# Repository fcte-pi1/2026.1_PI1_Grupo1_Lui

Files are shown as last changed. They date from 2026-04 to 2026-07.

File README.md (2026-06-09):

## Executando o Projeto (Software)

Para testar o Micromouse na sua máquina local, utilizamos um `Makefile` na raiz do projeto que facilita a inicialização simultânea de todos os serviços (Backend, Frontend e Simulador Mock).

**1. Instale as dependências (Primeira vez apenas):**
```bash
make install
```

**2. Rode todos os serviços juntos:**
```bash
make run
```

Ao fazer isso, o sistema irá subir o Backend Node.js, a Dashboard em React e o emissor de telemetria UDP do Mock em paralelo. Pressione `Ctrl + C` uma única vez para derrubar tudo.

Caso prefira rodar ou manipular módulos específicos:
- `make backend` (Sobe apenas o Node.js)
- `make frontend` (Sobe apenas a dashboard)
- `make mock` (Sobe o emissor UDP)
- `make build` (Gera a versão de produção do frontend)
- `make clean` (Apaga todas as pastas `node_modules` e pastas de `build` compiladas)

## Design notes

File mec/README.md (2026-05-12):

# 🏁 Labirinto Micromouse — Projeto em CATIA

> Modelagem 3D do labirinto para a competição **Micromouse** — Projeto Integrador 1 (PI1) | FCTE — 2026/1

---

## Tabela de Versionamento

| Versão | Descrição | Autor(es) | Revisor |
|---|---|---|---|
| 1.0 | Labirinto Micromouse — Projeto em CATIA | [Alexandre Macedo Alvarez](https://github.com/alexandremacedoalvarez-cpu) | iancostag, biancazero |

---

## 📌 Sobre o Projeto

Este repositório contém os arquivos de modelagem 3D (CATIA V5) do labirinto utilizado nos testes do robô autônomo *Micromouse*. O labirinto foi projetado para replicar fielmente as condições da competição oficial, sendo utilizado pela equipe como pista de testes durante o desenvolvimento do robô.

O *Micromouse* é um robô autônomo que resolve labirintos sem intervenção humana, mapeando o ambiente, monitorando sua localização e detectando quando alcançou o objetivo central.

---

## 📐 Especificações Técnicas

### Dimensões e Geometria

| Componente | Dimensões |
|---|---|
| **Pilar** | 5 mm × 5 mm |
| **Parede** | 180 mm (comprimento) × 50 mm (altura) |
| **Placa Base** | 720 mm × 720 mm |
| **Encaixe** | Furos de 5 mm × 5 mm nas extremidades das paredes |

### Configuração da Grade

- **Tipo:** 4×4 células
- **Lado total:** 720 mm
- **Tamanho de célula:** 18 cm × 18 cm
- **Espaçamento entre centros de pilares:** 175 mm
- **Vão livre (corredor):** 170 mm de largura — espaço suficiente para o robô (máx. 25 cm) manobrar sem colisões

> **Justificativa do espaçamento de 175 mm:** o conjunto de 5 pilares por linha cabe exatamente dentro da placa de 720 mm, sem extrapolação das bordas, enquanto mantém o corredor mínimo necessário para navegação do robô.

### Padrão de Cores

| Elemento | Cor |
|---|---|
| Corpo (paredes/pilares) | Branco  |
| Topo das peças | Vermelho  |
| Placa Base | Preto |

> As cores seguem o padrão oficial da competição Micromouse.

---

## 🔩 Decisões de Modelagem

- **Travamento mecânico modular:** as paredes possuem furos de 5×5 mm nas extremidades que encaixam sobre os pilares, criando uma estrutura firme e reconfigurável — o arranjo das paredes pode ser alterado para gerar diferentes labirintos.
- **Organização do modelo:** planos auxiliares e *constraints* foram ocultados na montagem final para limpeza visual do modelo.
- **Abordagem *bottom-up*:** as peças foram modeladas individualmente (`CATPart`) e depois montadas progressivamente em produtos (`CATProduct`), do nível de célula até o labirinto completo.

---

## 🎯 Contexto — Competição Micromouse (PI1 2026/1)

A equipe deve construir um robô autônomo capaz de resolver três labirintos de complexidade crescente:

| Labirinto | Grade | Dimensão |
|---|---|---|
| 1º | 4×4 | 72 cm |
| 2º | 8×8 | 144 cm |
| 3º | 16×16 | 288 cm |

**Este repositório cobre o labirinto 4×4 de testes**, construído pela equipe para desenvolvimento e validação do robô antes das etapas oficiais.

---

## 🛠️ Software Utilizado

- **CATIA V5** — Modelagem e montagem 3D

---

*Repositório seguindo o template disponibilizado em [github.com/fcte-pi1/template](https://github.com/fcte-pi1/template)*

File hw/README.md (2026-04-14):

# _Hardware_

Esta pasta deverá armazenar arquivos referentes a:

- Simulações de circuitos eletrônicos (alimentação, sensores, atuadores etc.): [Qucs](https://qucs.sourceforge.net/), [QSPICE](https://www.qorvo.com/design-hub/design-tools/interactive/qspice), [Fritzing](https://fritzing.org/), dentre outros.
- Esquemáticos de circuitos: [KiCad](https://www.kicad.org/), Qucs, QSPICE.
- Diagramas de bloco: [Canva](https://www.canva.com/pt_br/), [TikZ](https://tikz.net/).
- _Datasheets_ de componentes eletrônicos, microcontroladores, _shields_ Arduino, motores etc.
- Testes tabelados de circuitos: arquivos CSV, Excel.
- Imagens PNG e JPEG de resultados práticos: fotos de testes reais, gráficos de resultados etc.
- Outros arquivos referentes ao _hardware_ do projeto.

> [!WARNING]
> **Não acrescente código-fonte a esta pasta.** O código desenvolvido para microcontroladores e SOCs ([Arduino](https://www.arduino.cc/), [ESP32](https://www.espressif.com/), [Raspberry Pi](https://www.raspberrypi.com/)) deverá ser armazenado na pasta [src/firmware](https://github.com/fcte-pi1/template/tree/main/src/firmware) deste repositório.

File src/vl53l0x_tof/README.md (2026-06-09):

# VL53L0X ToF com ESP-IDF

Projeto ESP-IDF para ler um sensor ToF VL53L0X via I2C.

Este projeto usa o componente `ESP32_VL53L0X` copiado do projeto `example`, porque ele implementa o acesso de registrador do VL53L0X com indice de 8 bits. Os exemplos genericos de sensores I2C do ESP-IDF costumam assumir registradores de 16 bits e nao servem diretamente para esse sensor.

## Ligacao padrao

| VL53L0X | ESP32 |
| --- | --- |
| VIN/VCC | 3V3 |
| GND | GND |
| SDA | GPIO21 |
| SCL | GPIO22 |
| XSHUT | opcional |

O endereco I2C padrao do VL53L0X e `0x29`.

Se voce conectou o pino `XSHUT`, edite `main/app_main.cpp` e troque:

```cpp
constexpr gpio_num_t kXshutPin = GPIO_NUM_MAX;
```

por exemplo:

```cpp
constexpr gpio_num_t kXshutPin = GPIO_NUM_18;
```

## Build e flash

```sh
cd /home/mauricio/esp/vl53l0x_tof
. ../esp-idf/export.sh
idf.py set-target esp32
idf.py build
idf.py -p /dev/ttyUSB0 flash monitor
```

Troque `/dev/ttyUSB0` pela porta serial da sua placa.

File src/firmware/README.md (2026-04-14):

# _Firmware_
Esta pasta deverá armazenar arquivos referentes a:

- Código-fonte para microcontroladores e SOCs: [Arduino](https://www.arduino.cc/), [ESP32](https://www.espressif.com/), [Raspberry Pi](https://www.raspberrypi.com/), dentre outros.
- Projetos de organização destes códigos, caso utilize IDEs: [Arduino IDE](https://www.arduino.cc/en/software/), [Visual Studio](https://visualstudio.microsoft.com/pt-br/downloads/) etc.
- Arquivos de configuração: ```CMakeLists.txt``` se for usar [CMake](https://cmake.org/download/), ```Makefile``` se for usar [make](https://www.cs.colby.edu/maxwell/courses/tutorials/maketutor/) etc.

Evite incluir:
- Artefatos de compilação: os arquivos de saída compilados (binários, arquivos objeto, .hex, .elf) devem ser gerados pelo processo de compilação e não incluídos no repositório.
- Arquivos temporários/específicos do sistema operacional: Arquivos como .DS_Store (macOS) ou arquivos de configuração do editor (a menos que esteja usando uma configuração compartilhada como .editorconfig).
- Configurações pessoais: Arquivos de configuração locais específicos da máquina do desenvolvedor.

> [!WARNING]
> **Não acrescente arquivos referentes a _hardware_ nesta pasta.** Eles deverão ser armazenados na pasta [hw](https://github.com/fcte-pi1/template/tree/main/hw) deste repositório.

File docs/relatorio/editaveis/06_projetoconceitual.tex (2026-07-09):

\chapter{Projeto Conceitual do Produto}

\label{projeto}

\section{Características gerais}

%\textcolor{red}{Descrever produto de forma geral. Apresentar itens teóricos sobre o projeto a serem aprofundados ou detalhados oportunamente.}

%\textcolor{red}{Apresentar e explicar a Estrutura Analítica do Projeto (EAP), tomando cuidado com a legibilidade da imagem. Se necessário, coloque a EAP dentro do comando ``\textsf{\textbackslash begin\{landscape\} \textbackslash end\{landscape\}}'' para que ela seja apresentada em uma página deitada.}

O Micromouse é um robô móvel autônomo desenvolvido para mapear e resolver labirintos desconhecidos em matrizes de $4\times4$, $8\times8$ e $16\times16$ células, com o objetivo de alcançar a região central no menor tempo possível. O produto integra tecnologias multidisciplinares, unindo uma estrutura física compacta a um ecossistema de software para monitoramento em tempo real.

O hardware é baseado no microcontrolador ESP32, utilizando sensores laser Time-of-Flight (ToF) para detecção de obstáculos e motores N20 com encoders para odometria. O sistema de software provê a observabilidade através de um dashboard web que exibe dados de telemetria, como trajeto, velocidade e consumo de bateria via Wi-Fi.

Os itens teóricos fundamentais para o sucesso do projeto, que serão detalhados oportunamente, compreendem:

\begin{itemize}
    \item \textbf{Dinâmica e Estabilidade}: Cálculos de torque, potência e análise das condições de não-tombamento para garantir manobras seguras.
    \item \textbf{Gestão Energética}: Dimensionamento de baterias Li-Ion e eficiência de conversores DC-DC Buck para autonomia operacional.
    \item \textbf{Algoritmos de Navegação}: Aplicação de lógica Flood Fill para resolução de caminho e estratégias de exploração como DFS ou Tremaux.
    \item \textbf{Arquitetura de Sistemas}: Uso do FreeRTOS para processamento dual-core paralelo entre controle e telemetria.
\end{itemize}

\subsection{Estrutura Analítica do Projeto}

A Estrutura Analítica do Projeto (EAP) apresentada nesta seção é uma decomposição hierárquica orientada a entregas, porém, com foco no produto, organizada para facilitar o gerenciamento e o controle do escopo. O produto, e consequentemente o projeto, está dividido em cinco macroáreas principais:

\begin{itemize}
    \item \textbf{Estruturas (Laranja):} Abrange o desenvolvimento da estrutura física do robô e do labirinto de teste, incluindo base, chassi, fixações, rodas e organização mecânica.

    \item \textbf{Energia (Rosa):} Envolve a definição e integração do sistema de alimentação, incluindo bateria, reguladores de tensão, distribuição de energia e proteção do circuito.

    \item \textbf{Sistema de software (Verde):} Abrange o desenvolvimento da lógica de controle do robô, incluindo leitura dos sensores, controle dos motores, algoritmo de navegação e comunicação com o sistema embarcado.

    \item \textbf{Sistema eletrônico embarcado (Azul):} Envolve a integração dos componentes eletrônicos, como microcontrolador, sensores, driver dos motores, encoders e conexões elétricas do robô.

    \item \textbf{Sistema integrado (Roxo):} Abrange a integração entre estrutura, energia, eletrônica e software, incluindo montagem final, testes de funcionamento, ajustes e validação do robô no labirinto.
\end{itemize}

\begin{landscape}

\begin{figure}[p]
    \centering
    \includegraphics[
        width=\linewidth,
        height=0.80\textheight,
        keepaspectratio
    ]{figuras/eap.jpg}
    \caption{Visualização geral da Estrutura Analítica do Projeto.}
    \label{fig:eap-geral}
\end{figure}

\end{landscape}

\begin{landscape}

\begin{figure}[p]
    \centering

    \begin{minipage}{0.48\linewidth}
        \centering
        \includegraphics[
            width=\linewidth,
            height=0.72\textheight,
            keepaspectratio
        ]{figuras/eap_estruturas_energia.jpg}

        \vspace{0.2cm}
        \textbf{(a)} Primeira parte expandida do EAP.
    \end{minipage}
    \hfill
    \begin{minipage}{0.48\linewidth}
        \centering
        \includegraphics[
            width=\linewidth,
            height=0.72\textheight,
            keepaspectratio
        ]{figuras/eap_energia_embarcados_integrado.jpg}

        \vspace{0.2cm}
        \textbf{(b)} Segunda parte expandida do EAP.
    \end{minipage}

    \caption{Visualizações expandidas da Estrutura Analítica do Projeto.}
    \label{fig:eap-expandido}
\end{figure}

\end{landscape}

\section{Estrutura}
Esta seção descreve a síntese do projeto mecânico do Micromouse, desenvolvido sob uma perspectiva técnica e funcional. A estrutura foi projetada para equilibrar a rigidez necessária à precisão dos sensores com a leveza exigida para acelerações rápidas, respeitando rigorosamente as normas internacionais de competições de Micromouse.

Para a validação das escolhas de engenharia, este documento detalha os cálculos para determinação de dimensões e seleção dos motores, desenhos técnicos que materializam a geometria adotada e a especificação técnica dos materiais aplicados tanto no chassi quanto no labirinto de testes.

\subsection{Objetivo Geral}
Projetar e validar a estrutura física de um robô autônomo (Micromouse) e seu ambiente de simulação, garantindo uma plataforma estável, leve e de baixo custo, capaz de realizar navegação precisa e manobras de alta performance em conformidade com os padrões competitivos.

\subsubsection{Objetivos Específicos}
\begin{itemize}
    \item \textbf{Dimensionamento Geométrico:} Estabelecer as dimensões críticas do chassi (largura máxima de 110 mm) para garantir a manobrabilidade em trechos retilíneos e diagonais, evitando colisões com as paredes do labirinto.
    \item \textbf{Otimização Dinâmica:} Realizar o cálculo de torque e potência para a seleção do sistema motriz (GA12-N20), assegurando que o robô vença a inércia e mantenha a estabilidade (não-tombamento) em acelerações e frenagens bruscas.
    \item \textbf{Desenvolvimento Estrutural:} Projetar um chassi estratificado (dois níveis) que organize de forma estratégica a bateria, motores e sensores, otimizando o centro de massa e facilitando a manutenção dos componentes.
    \item \textbf{Seleção de Materiais:} Justificar o uso de materiais como PLA (impressão 3D) para o robô e MDF/EVA para o labirinto, focando na redução de peso e na qualidade da leitura dos sensores.
    \item \textbf{Padronização do Ambiente:} Construir um labirinto de testes modular que replique as condições reais de competição, permitindo a calibração fina dos algoritmos de busca e mapeamento.
\end{itemize}

\subsection{Dimensionamento Geométrico do Labirinto}

\subsubsection{Contexto e Normas do Labirinto}
O labirinto oficial da competição Micromouse é composto por células quadradas de $18{ cm} \times 18{ cm}$, medidos de centro a centro das paredes. As paredes laterais possuem $5{ cm}$ de altura e $1,2{ cm}$ de espessura. Esse padrão é adotado internacionalmente e define todas as restrições geométricas para o projeto do robô.

Considerando a espessura das paredes, o vão livre disponível para a movimentação do robô dentro de um corredor retilíneo é de:
\begin{equation}
18{ cm} - 1,2{ cm} = 16,8{ cm}
\end{equation}

Este valor é crítico porque representa o espaço real que o robô tem para efetuar o deslocamento sem tocar nas paredes laterais durante uma trajetória em linha reta. Além disso, para manobras que exigem uma rotação de $90^\circ$ ou travessia diagonal de uma célula, a geometria do labirinto impõe uma restrição mais severa: o robô não pode exceder a largura equivalente à diagonal do vão livre. O limite teórico para essa situação é:
\begin{equation}
{Largura diagonal} = 16,8{ cm} \div \sqrt{2} \approx 11,88{ cm}
\end{equation}

O projeto do chassi deve respeitar ambos os limites:
\begin{itemize}
    \item $\le 16,8{ cm}$ para trechos retos;
    \item $\le 11,88{ cm}$ para garantir operação em diagonal.
\end{itemize}

\subsubsection{Materiais e Construção do Labirinto Teste}
Para a construção do labirinto de testes, o projeto priorizou a modularidade e a fidelidade técnica às normas de competição. A estrutura baseia-se em uma malha de $4 \times 4$ células, totalizando $72{ cm}$ de lado, com vãos livres de $168{ mm}$.

Optou-se por uma base em \textbf{MDF de 6 mm}, visando planicidade e uniformidade. Para as paredes, utilizou-se \textbf{EVA de alta densidade de 12 mm}, que oferece leveza e segurança contra impactos. A montagem utiliza 25 postes removíveis ancorados à base por suportes metálicos em ``L''. As faces das paredes são revestidas com vinil branco fosco para otimizar os sensores ToF. O detalhamento geométrico completo (Figura \ref{fig:Desenho esquematoco do Labirinto de Testes}) ilustra o posicionamento dos postes e as dimesões da labirinto de testes. 

\subsection{Dimensionamento Geométrico do Chassi}

\subsubsection{Arranjo Preliminar dos Componentes}
\begin{itemize}
    \item \textbf{Bateria:} Posicionada na parte traseira para estabilizar o centro de massa.
    \item \textbf{Motores:} Localizados no centro do chassi para fornecer torque equilibrado às rodas.
    \item \textbf{Sensores:} Posicionados estrategicamente na dianteira para mapeamento e detecção de obstáculos.
\end{itemize}

\subsubsection{Desenho Esquemático}
O desenho técnico do chassi segue as larguras máximas de $160{ mm}$ (retilíneo) e $118,8{ mm}$ (diagonal). A vista explodida do Robô evidencia a hierarquia de montagem e as premissas de estabilidade dinâmica e fácil acesso à manutenção através da tampa
superior.

\subsubsection{Vistas Técnicas}
O desenho técnico do chassi (Figura \ref{fig:Draft Micromouse}) apresenta as principais dimensões e a localização de fixação dos componentes (motores, bateria e microcontrolador). As cotas estão expressas em milímetros e seguem as larguras máximas definidas anteriormente:
\begin{itemize}
    \item 160 mm para deslocamento retilíneo;
    \item 118,8 mm para manobras diagonais.
\end{itemize}

\subsubsection{Vista Explodida e Arranjo de Componentes}
A vista explodida do robô (Figura \ref{fig:Draft Micromouse explodido}) evidencia a disposição espacial dos 13 subsistemas principais, permitindo visualizar a hierarquia de montagem e a integração entre as partes mecânicas e eletrônicas.

\begin{table}[htbp]
\centering
\caption{Lista de Peças}
\label{tab:pecas_micromouse}
\begin{tabular}{@{}clc@{}}
\toprule
\textbf{Número} & \textbf{Nome} & \textbf{Quantidade} \\ \midrule
1 & Chassis & 1 \\
2 & Motor & 2 \\
3 & Bateria & 1 \\
4 & Microcontrolador & 1 \\
5 & Lateral & 2 \\
6 & Roda & 4 \\
7 & Engrenagem & 2 \\
8 & Protoboard 400 pinos & 1 \\
9 & Protoboard 170 pinos & 2 \\
10 & Tampa & 1 \\
11 & Sensor Laser VL53l0x & 3 \\
12 & Conversor DC-DC & 2 \\
13 & Driver para motor & 1 \\ \bottomrule
\end{tabular}
\end{table}

O arranjo foi projetado seguindo as seguintes premissas:

\begin{itemize}
    \item \textbf{Estabilidade Dinâmica:} A bateria (item 3) e os motores (item 2) estão fixados no chassi inferior (item 1), mantendo o centro de massa o mais próximo possível do solo e garantindo estabilidade em curvas.
    \item \textbf{Acesso à manutenção:} A tampa (item 10) permite a separação funcional dos componentes. Aqueles que não necessitam de acesso constante (motores, bateria) são alocados no chassi (item 1). Os elementos que exigem intervenção constante para depuração e calibração ficam acessíveis no plano superior. Além de prover proteção passiva, a tampa integra aberturas para o gerenciamento de cabos.
    \item \textbf{Interface de sensoriamento:} Os suportes dos sensores laser (item 11) foram posicionados nas extremidades da base, assegurando que o envelope de leitura não sofra interferência das rodas ou da tampa superior.
\end{itemize}

\subsubsection{Visão Isométrica}
A perspectiva isométrica do Micromouse (Figura \ref{fig:iso do micromouse}) consolida o design tridimensional, permitindo a visualização do robô em seu estado final de montagem.

\begin{itemize}
    \item \textbf{Validação volumétrica:} Demonstra a capacidade do conjunto e seu respeito às dimensões do labirinto.
\end{itemize}

\subsection{Dimensionamento dos Motores}

Pela Segunda Lei de Newton, a força trativa ($F_t$) deve superar a resistência ao rolamento ($F_{rr}$) para imprimir uma aceleração constante ($a$):

\begin{equation}
    C_{rr} = \frac{b}{R} \quad ; \quad F_{rr} = C_{rr} \cdot m \cdot g
\end{equation}

Onde $b$ é o coeficiente de atrito de rolamento, $R$ o raio da roda, $m$ a massa ($m \le 0,250{kg}$) e $g$ a aceleração da gravidade. A força trativa total é dada por:

\begin{equation}
    F_t = m \cdot (a + C_{rr} \cdot g)
\end{equation}

O torque mínimo ($T_{\min}$) e o torque de projeto com margem ($T_{{proj}}$) são definidos, respectivamente, pelas equações \ref{eq:torque_min} e \ref{eq:torque_projeto}:

\begin{equation}
    T_{\min} = F_t \cdot R
    \label{eq:torque_min}
\end{equation}

\begin{equation}
    T_{{proj}} = T_{\min} \cdot 1,3
    \label{eq:torque_projeto}
\end{equation}

\subsubsection{Desenvolvimento Matemático}

Adotou-se $b = 1,5{mm}$ (silicone sobre madeira pintada) e $R = 22,5{mm}$. Os cálculos seguem no Sistema Internacional (SI):

\begin{equation}
    F_{rr} = \left(\frac{1,5}{22,5}\right) \cdot 0,25 \cdot 9,81 = 0,1635{N}
\end{equation}

Logo, a força trativa para uma aceleração de $1{m/s}^2$ é:

\begin{equation}
    F_t = 0,25 \cdot 1 + 0,1635 = 0,4135{N}
\end{equation}

O torque mínimo total e o torque por motor (dividido por 2 com margem de 30\%) resultam em:

\begin{equation}
    T_{\min} \approx 9,31{N.mm} \Longrightarrow T_{\min\_{motor\_proj}} = \frac{9,31 \cdot 1,3}{2} = 6,0515{N.mm}
\end{equation}

\subsubsection{Conclusão e Validação}

Comparando os valores calculados com o \textit{datasheet} do motor \textbf{GA12-N20-S0310D-E}:

\begin{table}[htbp]
    \centering
    \caption{Validação do torque do motor GA12-N20}
    \label{tab:validacao-motor}
    \small
    \renewcommand{\arraystretch}{1.5}
    \begin{tabular}{|l|c|c|c|}
        \hline
        \textbf{Parâmetro} & \textbf{Valor Datasheet} & \textbf{Valor (N.mm)} & \textbf{Status} \\ \hline
        Torque Nominal     & 2,9~kg.mm                & 28,44~N.mm            & Validado ($> 6,05$) \\ \hline
        Torque de Estol    & 17~kg.mm                 & 166,71~N.mm           & Validado ($> 6,05$) \\ \hline
    \end{tabular}
\end{table}

\subsection{Condições de Não-Tombamento}

\subsubsection{Objetivo e Fundamentação Teórica}

O objetivo desta análise é determinar a altura máxima permitida para o Centro de Gravidade (CG), de forma a garantir que o veículo permaneça estável e não capote durante frenagens bruscas.

Na iminência de tombamento, a força Normal no eixo traseiro torna-se nula. A estabilidade é mantida enquanto o torque restaurador for superior ao torque de tombamento:

\begin{itemize}
    \item \textbf{Torque Restaurador:} Gerado pela componente vertical do peso.
    \item \textbf{Torque de Tombamento:} Gerado pela força de inércia resultante da desaceleração.
\end{itemize}

\subsubsection{Desenvolvimento Matemático}

A condição de estabilidade em relação ao eixo frontal é definida por:

\begin{equation}
    \tau_{{restaurador}} \geq \tau_{{tombamento}}\Longrightarrow P \cdot x \geq F \cdot h_{{máx}}
\end{equation}

Considerando que a força de desaceleração máxima é limitada pelo atrito estático ($\mu_e$), temos $F = P \cdot \mu_e$. Assim:

\begin{equation}
    P \cdot x \geq (P \cdot \mu_e) \cdot h_{máx}\Longrightarrow h_{{máx}} \le \frac{x}{\mu_e}
\end{equation}

Para uma distribuição de massa ideal, onde o CG está no centro geométrico ($x = L/2$):

\begin{equation}
    h_{{máx}}\le\frac{L}{2\cdot\mu_e}
\end{equation}

Dados os parâmetros do projeto:
\begin{itemize}
    \item $\mu_e = 0,7$
    \item $L = 0,1225~{m}$
\end{itemize}

\begin{equation}
    h_{máx}\le \frac{0,1225}{2 \cdot 0,7} \approx 0,0875{m} \Longrightarrow h_{máx} \le 8,75{cm}
\end{equation}

\subsubsection{Conclusão}
A análise do projeto mecânico confirma que o robô está tecnicamente apto para a competição. Com largura de $110{ mm}$ e centro de gravidade otimizado, o Micromouse garante agilidade sem risco de colisões ou tombamentos. O sistema motriz validado e o labirinto de testes fiel às normas consolidam uma base sólida para a integração final dos algoritmos de navegação autônoma.

\section{Análise de consumo energético}

Esta seção apresenta o dimensionamento energético do sistema embarcado do MicroMouse, considerando os componentes eletrônicos utilizados, o tempo estimado de operação e a escolha da fonte de alimentação. O objetivo é estimar o consumo total do sistema e justificar a escolha da bateria utilizada no projeto.

\subsection{Parâmetros considerados}

Para o dimensionamento energético, considerou-se o uso do sistema durante \textbf{1080 segundo (s)}, o equivalente a 18 minutos. Esse tempo foi definido levando em conta 9 tentativas, por ser o máximo de tentativas possíveis durante a prova, e a duração de 2 minutos por tentativa.

Também foi adotada uma margem de segurança de 30\% sobre o consumo total estimado, a fim de reduzir o risco de subdimensionamento da bateria e garantir maior confiabilidade ao sistema.

\subsection{Relação dos componentes}

A Tabela~\ref{tab:componentes-energia} apresenta os principais componentes eletrônicos considerados no cálculo energético do sistema.

\begin{table}[htbp]
\centering
\caption{Componentes considerados no dimensionamento energético}
\label{tab:componentes-energia}
\small
\setlength{\tabcolsep}{4pt}
\renewcommand{\arraystretch}{1.2}
\begin{tabularx}{\textwidth}{|>{\raggedright\arraybackslash}X|c|c|c|c|}
\hline
\textbf{Componente} & \textbf{Qtd.} & \textbf{Tensão (V)} & \textbf{Corrente (A)} & \textbf{Tempo (s)} \\ \hline

ESP WROOM-32 / ESP32 DevKit V1 
& 1 & 5 & 0,08 a 0,5 & 1080 \\ \hline

Motor GA-12 N20 DC com encoder 
& 2 & 6 & 0,08 a 1,6 & 1080 \\ \hline

Sensor ToF VL53L0X 
& 3 & 2,8 & 0,02 & 1080 \\ \hline

Sensor INA219 
& 1 & 3,3 & 0,001 & 1080 \\ \hline

\end{tabularx}
\end{table}

A Ponte H TB6612FNG não foi contabilizada diretamente no dimensionamento energético, pois atua como intermediária no acionamento dos motores. Dessa forma, o consumo dos motores GA-12 N20 já representa a maior parte da corrente que passa por ela. O consumo próprio da lógica interna da TB6612FNG é muito pequeno em relação ao consumo total do sistema e, por isso, foi considerado desprezível para este cálculo.

\subsection{Cálculo da energia consumida por componente}

A energia consumida por cada componente foi calculada por meio da 
Equação~\ref{eq:energia}, utilizando os parâmetros de tensão, corrente 
e tempo listados na Tabela~\ref{tab:componentes-energia}.

\begin{equation}
E_{J} = V \cdot I \cdot t
\label{eq:energia}
\end{equation}

No qual $E$ representa a energia consumida em joules (J), $V$ é a tensão 
de operação em volts (V), $I$ é a corrente elétrica em amperes (A) e 
$t$ é o tempo de uso em segundos (s). Para os componentes com faixa de 
corrente, adotou-se o valor máximo, representando o pior caso de consumo.

Para converter o resultado de joules para watt-hora(Wh), utilizou-se a 
relação da Equação~\ref{eq:conversao_j_wh}:

\begin{equation}
E_{Wh} = \frac{E_{J}}{3600}
\label{eq:conversao_j_wh}
\end{equation}

A Tabela~\ref{tab:consumo-individual} apresenta, para cada componente, 
a aplicação da Equação~\ref{eq:energia} com os parâmetros da 
Tabela~\ref{tab:componentes-energia}, o resultado em joules,
conversão para watt-hora pela Equação~\ref{eq:conversao_j_wh} e o resultado em watt-hora.

\begin{table}[h]
\centering
\caption{Consumo energético individual dos componentes em 18 minutos}
\label{tab:consumo-individual}
\resizebox{\linewidth}{!}{
\begin{tabular}{|l|l|c|c|c|}
\hline
\textbf{Componente} & \textbf{Equação \ref{eq:energia}} & \textbf{Energia (J)} & \textbf{Equação \ref{eq:conversao_j_wh}} & \textbf{Energia (Wh)} \\ \hline
ESP32 DevKit V1 & $E_{J} = 5 \cdot 0{,}5 \cdot 1080$ & 2700 &  $E_{Wh} = 2070 \div 3600 $ & 0,75 \\ \hline
Motor GA-12 N20 & $E_{J} = 6 \cdot 1{,}6 \cdot 1080$ & 10368 & $E_{Wh} = 10368 \div 3600 $  & 2,88 \\ \hline
Sensor ToF VL53L0X & $E_{J} = 2{,}8 \cdot 0{,}02 \cdot 1080$ & 60,48 & $E_{Wh} = 60,48 \div 3600 $ & 0,0168 \\ \hline
Sensor INA219 & $E_{J} = 3{,}3 \cdot 0{,}001 \cdot 1080$ & 3,564 & $E_{Wh} = 3,564 \div 3600 $ & 0,001 \\ \hline
\end{tabular}
}
\end{table}

\subsection{Estimativa do consumo total de energia}

Para obter o consumo total, o consumo individual de cada componente foi multiplicado pela respectiva quantidade utilizada no sistema, conforme apresentado na Tabela~\ref{tab:consumo-total}.

\begin{table}[htbp]
\centering
\caption{Consumo total estimado do sistema}
\label{tab:consumo-total}
\small
\setlength{\tabcolsep}{4pt}
\renewcommand{\arraystretch}{1.2}
\begin{tabularx}{\textwidth}{|>{\raggedright\arraybackslash}X|c|c|c|}
\hline
\textbf{Componente} 
& \textbf{Qtd.} 
& \shortstack{\textbf{Consumo}\\\textbf{individual}\\\textbf{(Wh)}} 
& \shortstack{\textbf{Consumo}\\\textbf{total}\\\textbf{(Wh)}} \\ \hline

ESP32 DevKit V1 
& 1 
& 0,75 
& 0,75 \\ \hline

Motor GA-12 N20 DC com encoder 
& 2 
& 2,88 
& 5,76 \\ \hline

Sensor ToF VL53L0X 
& 3 
& 0,0168 
& 0,0504 \\ \hline

Sensor INA219 
& 1 
& 0,001 
& 0,001 \\ \hline

\textbf{Total final} 
& -- 
& -- 
& \textbf{6,5614} \\ \hline

\end{tabularx}
\end{table}

Portanto, o consumo total estimado para 18 minutos de operação é de aproximadamente:

\begin{equation}
E_{total} \approx 6{,}56\,Wh
\end{equation}

Aplicando uma margem de segurança de 30\%:

\begin{equation}
E_{folga} = 6{,}56 \cdot 1{,}30 \approx 8{,}53\,Wh
\end{equation}

Assim, a fonte de alimentação deve ser dimensionada para fornecer, no mínimo, aproximadamente \textbf{$8{,}53\,Wh$}.

\subsection{Escolha da fonte de alimentação}

Para escolher a fonte de alimentação do sistema, foi utilizada a relação entre energia, tensão e capacidade, apresentada na Equação~\ref{eq:capacidade}.

\begin{equation}
Capacidade = \frac{E}{V}
\label{eq:capacidade}
\end{equation}

Onde a capacidade é dada em ampère-hora (Ah), $E$ representa a energia necessária em watt-hora (Wh) e $V$ representa a tensão da bateria em volts (V).

Considerando a energia com folga de $8{,}53\,Wh$, foram analisadas duas possibilidades de tensão: $7{,}4\,V$ e $12\,V$.

\begin{table}[htbp]
\centering
\caption{Capacidade mínima sem considerar a profundidade de descarga}
\label{tab:capacidade-minima}
\begin{tabular}{|c|c|c|}
\hline
\textbf{Tensão da bateria} & \textbf{Cálculo} & \textbf{Capacidade mínima} \\ \hline
$7{,}4\,V$ & $8{,}53 \div 7{,}4$ & $1{,}16\,Ah$ \\ \hline
$12\,V$ & $8{,}53 \div 12$ & $0{,}71\,Ah$ \\ \hline
\end{tabular}
\end{table}

Ao dimensionar a bateria, recomenda-se considerar apenas parte da capacidade nominal como capacidade útil, evitando descargas excessivas e preservando a vida útil da bateria. Neste projeto, foram adotados os seguintes valores: \textbf{80\% de capacidade útil para baterias Li-Ion e 70\% de capacidade útil para baterias LiPo}.

\begin{table}[htbp]
\centering
\caption{Capacidade mínima corrigida considerando a capacidade útil da bateria}
\label{tab:capacidade-corrigida}
\begin{tabular}{|l|c|c|}
\hline
\textbf{Tipo de bateria} & \textbf{7,4 V} & \textbf{12 V} \\ \hline
Li-Ion & $1{,}16 / 0{,}8 \approx 1{,}46\,Ah$ & $0{,}71 / 0{,}8 \approx 0{,}89\,Ah$ \\ \hline
LiPo & $1{,}16 / 0{,}7 \approx 1{,}66\,Ah$ & $0{,}71 / 0{,}7 \approx 1{,}01\,Ah$ \\ \hline
\end{tabular}
\end{table}

\subsection{Fonte de alimentação escolhida}

A fonte de alimentação escolhida foi uma \textbf{bateria Li-Ion de $7{,}4\,V$ e $2500\,mAh$ com BMS}, considerando o custo-benefício em relação às baterias LiPo e a compatibilidade com o sistema embarcado.

Como a capacidade mínima calculada para uma bateria Li-Ion de $7{,}4\,V$ foi de aproximadamente $1{,}46\,Ah$, a bateria escolhida, com $2{,}5\,Ah$, atende ao requisito de autonomia com margem adicional de segurança.

A energia nominal da bateria escolhida é dada por:

\begin{equation}
E = V \cdot Ah
\end{equation}

\begin{equation}
E = 7{,}4 \cdot 2{,}5 = 18{,}5\,Wh
\end{equation}

Considerando o uso recomendado de 80\% da capacidade para baterias Li-Ion:

\begin{equation}
E_{util} = 18{,}5 \cdot 0{,}8 = 14{,}8\,Wh
\end{equation}

Como a energia útil disponível é maior do que a energia necessária com folga, sendo \textbf{14{,}8\,Wh > 8{,}53\,Wh}, conclui-se que a bateria escolhida \textbf{atende ao consumo estimado do sistema para 18 minutos de operação}.

\subsection{Estimativa de autonomia}

Considerando que o sistema consome aproximadamente $6{,}56\,Wh$ em 18 minutos, o consumo médio em potência é:

\begin{equation}
P_{media} = \frac{6{,}56\,Wh}{0{,}3\,h} \approx 21{,}87\,W
\end{equation}

Usando a energia útil da bateria escolhida:

\begin{equation}
Autonomia = \frac{14{,}8\,Wh}{21{,}87\,W} \approx 0{,}67\,h \approx 40\,min
\end{equation}

Portanto, a bateria escolhida possui autonomia estimada de aproximadamente \textbf{40 minutos}, considerando o consumo calculado. Caso seja considerada a margem de segurança de 30\% como consumo adicional, a autonomia estimada fica próxima de 31 minutos, ainda superior aos 18 minutos exigidos. Cabe frizar que a bateria escolhida pelo grupo é \textbf{recarregável}, o que possibilita sua reutilização em diferentes testes e ciclos de operação, a fim de reduzir a necessidade de substituição frequente e torna a solução mais prática e econômica para o projeto.

\subsection{Planejamento do circuito de alimentação}

A tensão de \textbf{$7{,}4\,V$} foi escolhida por ser adequada para o sistema embarcado, e serão utilizados de \textit{\textbf{bucks}} para formar reguladores de tensão nas entradas necessárias, protegendo a ESP32 e a ponte H contra tensões acima do limite permitido.

\subsection{Proteção da bateria com BMS}

O BMS, sigla para \textit{Battery Management System}, ou sistema de gerenciamento de bateria, é responsável por proteger as células contra condições inseguras de operação. Esse circuito auxilia na proteção contra sobrecarga, descarga excessiva e, dependendo do modelo, sobrecorrente e curto-circuito.

Mesmo com o uso do BMS, é necessário verificar se ele suporta a corrente máxima exigida pelo sistema, principalmente durante a partida dos motores, momento em que a corrente pode ser maior do que durante o funcionamento normal.

\subsection{Monitoramento via \textit{software}}

O monitoramento energético será realizado por meio do \textit{software} embarcado a ser implementado na ESP32, utilizando o sensor INA219 para acompanhar grandezas elétricas do sistema, como tensão e corrente. A comunicação com o sensor será feita por meio do barramento $I^2C$, o que permite a coleta periódica dos dados durante a operação do carrinho.

As rotinas implementadas no \textit{firmware} terão como objetivo registrar a tensão da bateria, estimar o tempo de operação e acompanhar possíveis variações no consumo de energia. Esses dados serão enviados para a aplicação de acompanhamento do sisstema. 

Além disso, o monitoramento também contribuirá para a segurança do projeto, ao permitir identificar situações de queda excessiva de tensão na bateria. Caso a tensão atinja níveis críticos, o sistema poderá acionar alertas ou executar procedimentos de parada segura antes que ocorra descarga excessiva das células. Isso complementa ainda mais a utilização do BMS.

\subsection{Validação com testes reais}

A validação do dimensionamento energético será realizada por meio de testes práticos com o MicroMouse em operação. O objetivo desses testes será comparar o consumo estimado teoricamente com o consumo real observado durante o funcionamento do sistema.

Durante os testes, serão analisados dados como tempo de operação, queda de tensão da bateria e comportamento do consumo em diferentes condições de movimentação, como aceleração, curvas e deslocamento contínuo. Com isso, será possível validar se a bateria escolhida atende adequadamente à autonomia necessária para o projeto, como verificado no projeto conceitual.

Caso sejam observadas diferenças relevantes entre os valores teóricos e experimentais, elas serão analisadas considerando fatores como perdas nos reguladores de tensão, variações na corrente dos motores, atrito mecânico, eficiência dos conversores e oscilações naturais da carga durante a operação. Assim, será possível refinar o dimensionamento energético e ajustar o sistema, se necessário.

\subsection{Conclusão}

Com base nos cálculos realizados, o sistema apresenta consumo estimado de aproximadamente $6{,}56\,Wh$ para 18 minutos de operação. Aplicando uma margem de segurança de 30\%, a energia necessária sobe para $8{,}53\,Wh$.

A bateria escolhida, uma Li-Ion de $7,4V$ e $2500mAh$ com BMS, possui energia nominal de aproximadamente $18,5\,Wh$ e energia útil estimada de $14,8\,Wh$, considerando 80\% de capacidade utilizável. Portanto, ela atende aos requisitos energéticos do projeto com margem de segurança, além de apresentar bom custo-benefício e compatibilidade com o sistema embarcado.

\section{Descrição de \textit{software}}

Esta seção tem como objetivo descrever os artefatos gerados pela equipe de software, entre eles estão: Diagrama de atividades UML, backlog do produto e requisitos, a arquitetura de solução de software e o roteriro de testes funcionais.

\subsection{Diagrama de Atividades UML}

\begin{figure}[htpb]
    \centering
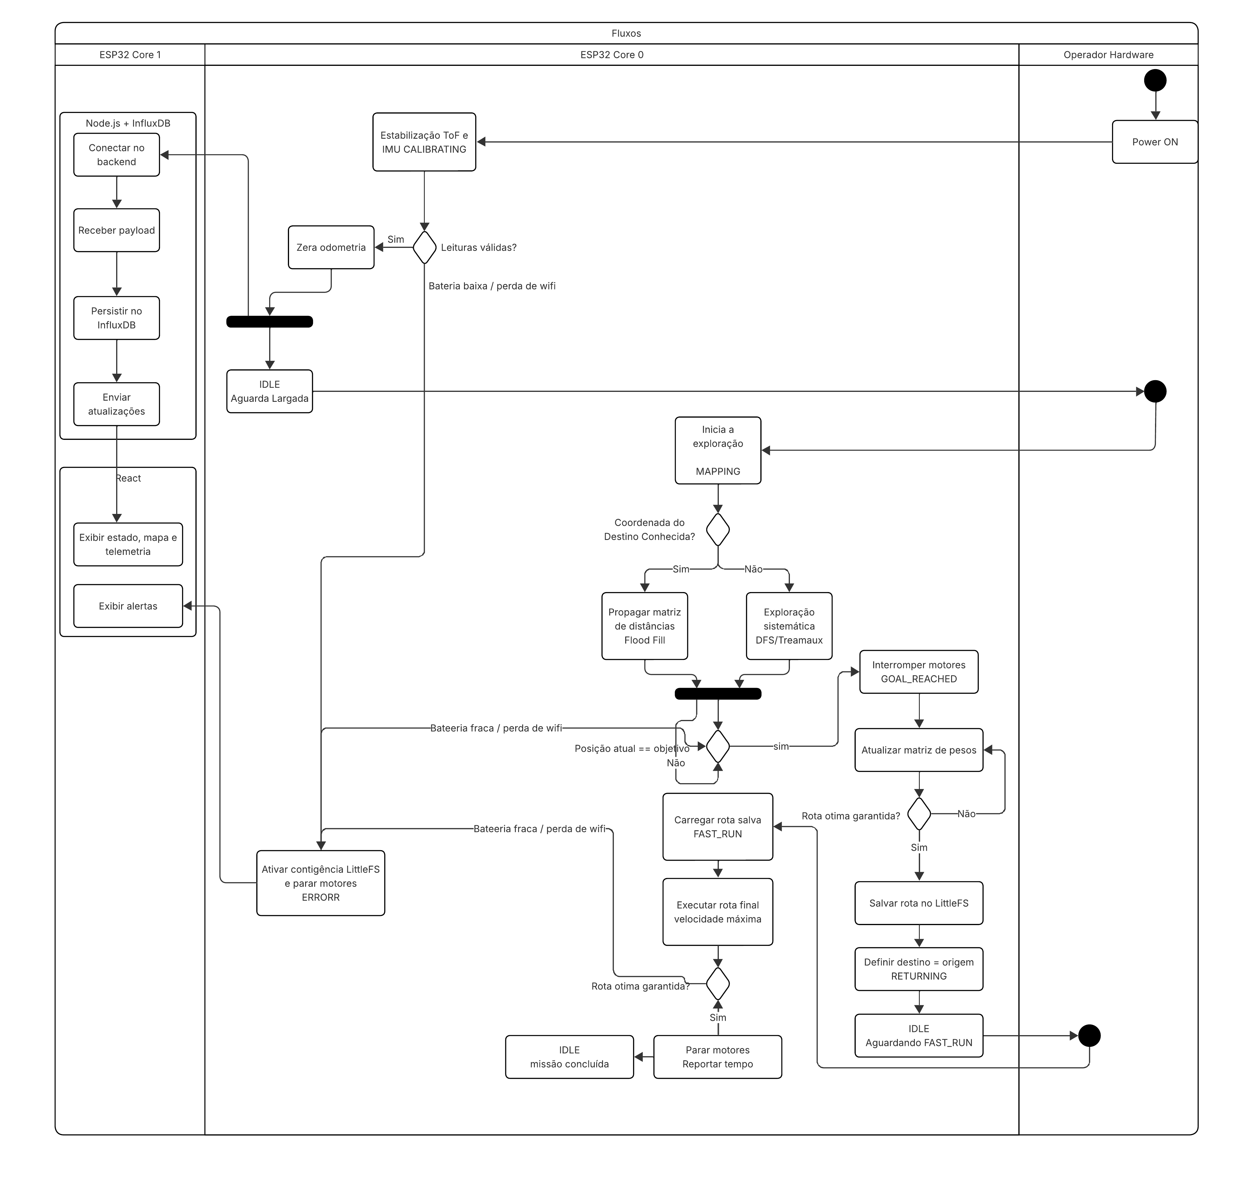
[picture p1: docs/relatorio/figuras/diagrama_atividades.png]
    
    \caption{Diagrama de Atividades UML do ecossistema Micromouse.}
    \label{fig:diagrama_atividades}
\end{figure}

O Diagrama de Atividades UML do ecossistema Micromouse é organizado em três
\textit{swimlanes} --- Operador/Hardware, ESP32 Core~0 e ESP32 Core~1 --- e
descreve o comportamento funcional do sistema ao longo de cada fase da missão.
Após o \textit{power on}, o Core~0 realiza a calibração dos sensores ToF e IMU
e, uma vez validadas as leituras, zera a odometria e avança para o estado
\texttt{IDLE}. Em seguida, um \textit{fork} dispara dois fluxos paralelos: o
Core~0 assume o controle de movimento e a FSM, enquanto o Core~1 transmite
telemetria continuamente para o \textit{backend} (Node.js + InfluxDB) e o
Dashboard em React.
Flood Fill; caso contrário, adota a exploração sistemática por DFS/Tremaux.

Na fase de exploração (\texttt{MAPPING}), o Core~0 aplica uma abordagem
híbrida: caso o destino já seja conhecido, propaga a matriz de distâncias via
O ciclo se repete até que o centro do labirinto seja atingido
(\texttt{GOAL\_REACHED}), momento em que os motores são interrompidos e a rota
ótima é calculada com base no mapa construído.

Com a rota confirmada, o destino é redefinido como a origem e o robô executa o
retorno (\texttt{RETURNING}) com controle PID, salvando o trajeto no sistema de
arquivos LittleFS. O sistema volta ao estado \texttt{IDLE} até o operador
acionar o \texttt{FAST\_RUN}, fase em que o robô percorre a rota em velocidade
máxima e reporta o tempo final. Em qualquer fase crítica, transições pontilhadas
desviam o fluxo para o estado \texttt{ERROR}, que paralisa os motores, exibe
alerta no Dashboard e aguarda o reset físico do operador.

\subsection{Backlog do Produto e Requisitos}
    \subsubsection{Backlog do Produto}
    O escopo completo da solução de \textit{software} englobando a ingestão de telemetria, o processamento de estados e a visualização no painel de controle (\textit{Dashboard})  foi especificado através de Histórias de Usuário (HUs) cobrindo a totalidade dos requisitos funcionais e operacionais. A priorização de todos os itens seguiu a classificação MoSCoW (\textit{Must have}, \textit{Should have}, \textit{Could have}, \textit{Won't have}), garantindo total rastreabilidade com os testes funcionais do sistema. A tabela contendo as histórias de usuário pode ser encontrada no backlog completo.

    \begin{figure}[htpb]
    \centering
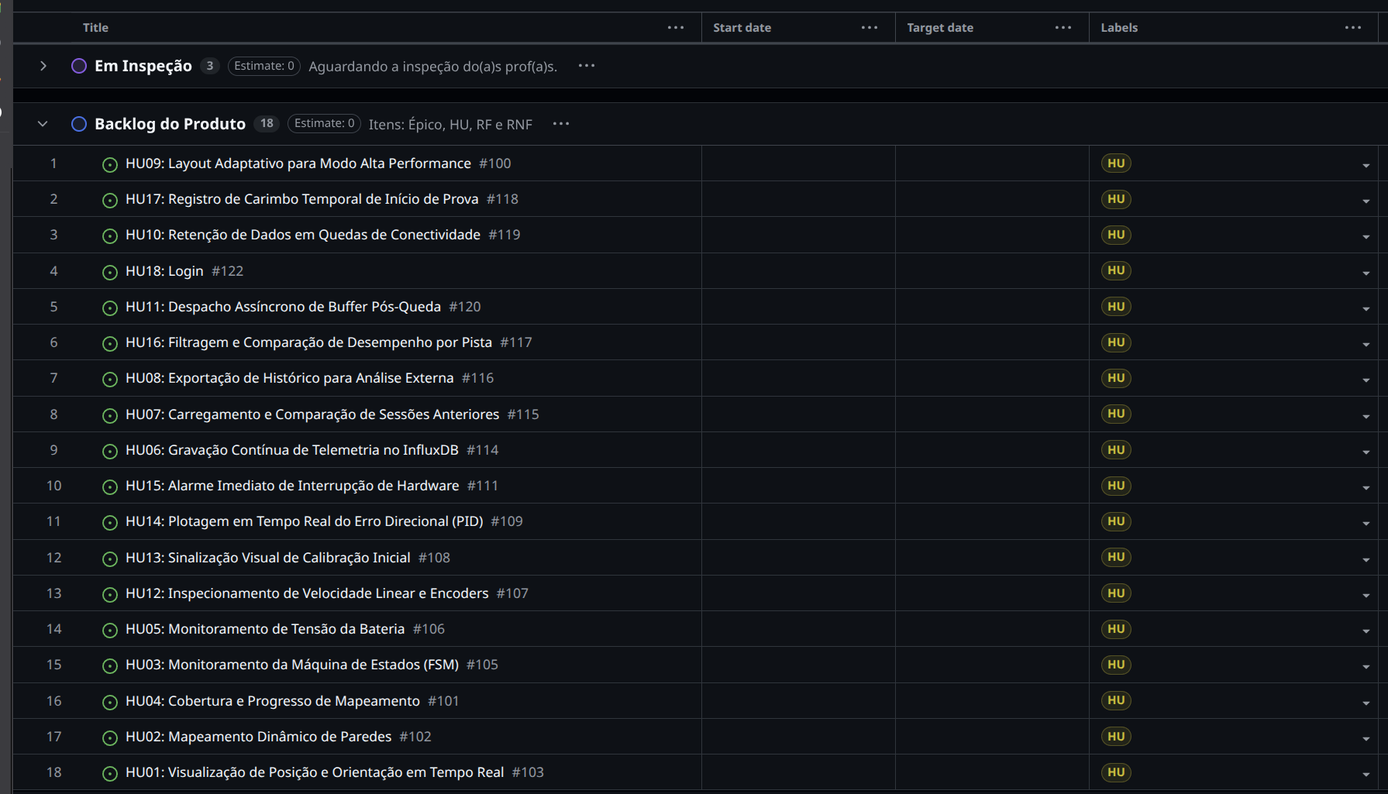
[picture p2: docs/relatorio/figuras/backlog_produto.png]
    
    \caption{Backlog do Produto}
    \label{fig:esquema-eletrico}
\end{figure}

    \subsubsection{Requisitos Funcionais e Não Funcionais}
        
    Os \textbf{Requisitos Funcionais (RF)} concentram-se na autonomia do robô: a capacidade de percepção visual do labirinto através de sensores ToF, o mapeamento interno da matriz virtual e o processamento local de algoritmos de busca de caminho. Adicionalmente, estabelecem a obrigatoriedade da transmissão de telemetria para monitoramento externo.
    
    Os \textbf{Requisitos Não Funcionais (RNF)} definem os critérios de qualidade e as restrições de contorno. Estes abrangem desde métricas de desempenho de software (como a latência máxima de transmissão) até especificações físicas rigorosas da estrutura (limites dimensionais de 10 cm de largura e massa inferior a 250 g), passando pela autonomia energética para múltiplas execuções consecutivas.
    
    Dada a natureza multidisciplinar e o rigor técnico exigido para a validação de cada item, a listagem exaustiva e a origem de cada um dos requisitos funcionais e não funcionais unificados encontram-se detalhadas no \autoref{apice:requisitos_unificados}.
                
    \subsection{Arquitetura de Solução de Software}
    
    A arquitetura do sistema é estruturada segundo as visões (4+1) do Processo Unificado (UP), segmentando a solução sob as óticas lógica, de processos, de implementação, de implantação e de dados para contemplar os requisitos multidisciplinares do Micromouse.
    
    \subsubsection{Visão Lógica}
    A visão lógica define as abstrações fundamentais, o propósito e as estratégias de navegação autônoma. O propósito do firmware embarcado é garantir a exploração e o planejamento de trajetória, enquanto a aplicação web provê a observabilidade do sistema em tempo real.

\begin{itemize}
    \item \textbf{Padrão Adotado (Arquitetura)}: O firmware adota o padrão orientado a eventos (\textit{Event-Driven Streaming}) para desacoplar a leitura de sensores da transmissão de pacotes. O Dashboard web adota o padrão baseado em Componentes com gerenciamento de estado reativo (evoluído do MVC), justificando-se pela necessidade de atualizar múltiplas métricas simultaneamente sem bloquear a interface.
    \item \textbf{Representação do Ambiente}: O labirinto é modelado como uma grade bidimensional discreta, onde cada célula armazena informações de paredes (Norte, Sul, Leste, Oeste) e estado de visitação.
    \item \textbf{Algoritmo de Navegação}: Utiliza-se o algoritmo \textit{Flood Fill} para propagar distâncias a partir da célula objetivo para as demais posições. A decisão de movimento baseia-se na seleção do vizinho acessível com o menor valor na matriz de distâncias.
    \item \textbf{Estratégia de Desempate}: Em situações de distâncias iguais, prioriza-se a manutenção da direção atual (seguindo a ordem: reta $>$ leve curva $>$ curva forte $>$ retorno) para minimizar curvas desnecessárias.
    \item \textbf{Abordagem Híbrida}: Em cenários de destino desconhecido, utiliza-se inicialmente DFS ou Tremaux para exploração sistemática, alternando para \textit{Flood Fill} assim que o objetivo é detectado.
\end{itemize}

\subsubsection{Visão de Processos}
\begin{itemize}
    \item \textbf{Processamento Dual-Core}: O microcontrolador ESP32 distribui as tarefas de forma assíncrona utilizando o FreeRTOS \cite{freertos_documentation}, o Core 0 é dedicado ao controle PID, enquanto o Core 1 gerencia a transmissão de dados via Wi-Fi, evitando interferências no movimento do robô.
    \item \textbf{Máquina de Estados Finitos (FSM)}: O firmware opera sob estados determinísticos que ditam o ciclo de vida do robô:
    \begin{itemize}
        \item \texttt{CALIBRATING}: Estabilização de sensores ToF e IMU.
        \item \texttt{IDLE}: Estado de repouso aguardando comandos.
        \item \texttt{MAPPING}: Exploração ativa e construção do mapa.
        \item \texttt{GOAL\_REACHED}: Confirmação de chegada ao centro.
        \item \texttt{RETURNING}: Retorno à base após cálculo da rota ótima.
        \item \texttt{FAST\_RUN}: Execução da rota otimizada em velocidade máxima.
        \item \texttt{ERROR}: Estado disparado por falhas críticas como bateria baixa (via INA219) ou perda de Wi-Fi.
    \end{itemize}
\end{itemize}
O diagrama da máquina de estados pode ser encontrado no \autoref{apice:maquina_de_estados}

\subsubsection{Visão de Implementação}
Descreve as linguagens e frameworks que compõem os blocos do sistema.

\begin{itemize}
    \item \textbf{Firmware (C++)}: Desenvolvido em linguagem C++ nativa, utilizando serialização MsgPack (\textit{ArduinoJson}) para otimizar o payload de telemetria, Além disso, a lógica de controle dos sensores e dos motores será organizada em \textit{tasks} do FreeRTOS \cite{freertos_documentation}.
    \item \textbf{Front-end (JavaScript/React)}: Construído em JavaScript (ES6+) utilizando a biblioteca React com Vite e Tailwind CSS. A renderização gráfica do labirinto utiliza a HTML5 Canvas API para garantir fluidez na visualização do trajeto.
    \item \textbf{Back-end (JavaScript/Node.js)}: Serviço estruturado em Node.js responsável por receber pacotes UDP e convertê-los para o protocolo de linha do InfluxDB.
\end{itemize}

\subsubsection{Visão de Implantação}
Mapeia a topologia física e a distribuição dos nós de processamento.

\begin{itemize}
    \item \textbf{Transporte de Dados}: Comunicação não-bloqueante via UDP (\textit{AsyncUDP}) com latência estimada entre 1--5 ms entre o robô e a estação base.
    \item \textbf{Fluxo de Telemetria}: ESP32 $\rightarrow$ Node.js $\rightarrow$ InfluxDB $\rightarrow$ Navegador (via WebSockets).
    \item \textbf{Resiliência}: Uso de LittleFS via SDMMC para armazenamento local contingencial em caso de falha na rede Wi-Fi.
\end{itemize}

\subsubsection{Visão de Dados (Persistência)}

Para suportar o alto volume de dados gerado em frequências de até 1 kHz, adotou-se o \textbf{InfluxDB}, um banco de dados de séries temporais (TSDB). A modelagem lógica abandona o esquema relacional tradicional em favor de um paradigma de \textit{Tags} (metadados indexados em memória) e \textit{Fields} (métricas dinâmicas gravadas em disco).

\begin{table}[htbp]
\centering
\caption{Modelagem de Dados no InfluxDB (Measurement: \texttt{log\_corrida})}
\label{tab:schema_influxdb}
\begin{tabular}{|l|l|l|}
\hline
\textbf{Tipo} & \textbf{Atributo} & \textbf{Descrição / Origem} \\ \hline
\textit{Primary Key} & \texttt{time} & Timestamp em nanossegundos \\ \hline
\textit{Tags} & \texttt{id\_labirinto} & Dimensão (ex: 16x16, 8x8) \\ \cline{2-3} 
 & \texttt{id\_corrida} & Identificador único da tentativa \\ \cline{2-3} 
 & \texttt{objetivo} & Status de conclusão (S/N) \\ \cline{2-3} 
 & \texttt{estado\_robo} & Estado da FSM embarcada \\ \hline
\textit{Fields} & \texttt{pos\_x}, \texttt{pos\_y} & Coordenadas na matriz do labirinto \\ \cline{2-3} 
 & \texttt{orientacao} & Ângulo azimutal ($\theta$) via IMU/Odometria \\ \cline{2-3} 
 & \texttt{bateria} & Tensão instantânea (Volts) via ADC1 \\ \cline{2-3} 
 & \texttt{erro\_pid} & Erro de desvio do laço de controle \\ \cline{2-3} 
 & \texttt{dist\_frontal} & Leitura do sensor ToF Frontal (mm) \\ \cline{2-3} 
 & \texttt{dist\_esq} & Leitura do sensor ToF Esquerdo (mm) \\ \cline{2-3} 
 & \texttt{dist\_dir} & Leitura do sensor ToF Direito (mm) \\ \cline{2-3} 
 & \texttt{pwm\_esq}, \texttt{pwm\_dir} & Sinal aplicado aos motores N20 \\ \cline{2-3} 
 & \texttt{velocidade\_media} & Velocidade linear (m/s) via encoders \\ \hline
\end{tabular}
\end{table}

\subsection{Roteiro de Testes Funcionais}

A validação da solução de \textit{software} fundamenta-se na execução de um roteiro de testes funcionais do tipo "caixa-preta", cujo objetivo é assegurar que todas as Histórias de Usuário descritas no \textit{backlog} operem conforme os critérios de aceitação estipulados. Este roteiro foca na integridade do fluxo de dados --- desde a captura sensorial no microcontrolador ESP32 até a renderização gráfica no \textit{Dashboard} --- e na resiliência do sistema sob condições de falha de rede ou estresse de carga.

Cada caso de teste foi estruturado para fornecer rastreabilidade total, contendo identificação única, objetivos claros, pré-condições operacionais, procedimentos passo a passo e os resultados esperados para aprovação. Essa estrutura permite que a equipe realize auditorias periódicas e garanta que novas atualizações no \textit{firmware} não causem regressões nas funcionalidades de telemetria e controle.

Devido à densidade técnica e à extensão do plano de testes, que compreende 14 cenários distintos de validação, o roteiro completo encontra-se detalhado no \autoref{apice:roteiro_testes}.

\section{Descrição de Hardware}

Esta seção apresenta a arquitetura eletrônica do sistema embarcado do Micromouse, abordando os principais componentes responsáveis pelo controle, sensoriamento, acionamento dos motores e alimentação do robô. São descritos os dispositivos utilizados no projeto, suas funções no sistema e a forma como os módulos eletrônicos se integram para garantir o funcionamento da plataforma. Além disso, são apresentados o diagrama de blocos da arquitetura, o mapeamento de comunicação entre os dispositivos e o esquemático eletrônico desenvolvido para o circuito do robô.

\subsection{Visão geral da arquitetura}

A arquitetura do sistema embarcado será representada por meio de um diagrama de blocos, com o objetivo de mostrar a organização geral do robô e a interação entre seus principais módulos. Nele são apresentados os blocos de alimentação, processamento, sensoriamento, acionamento dos motores e comunicação.

\begin{figure}[htpb]
    \centering
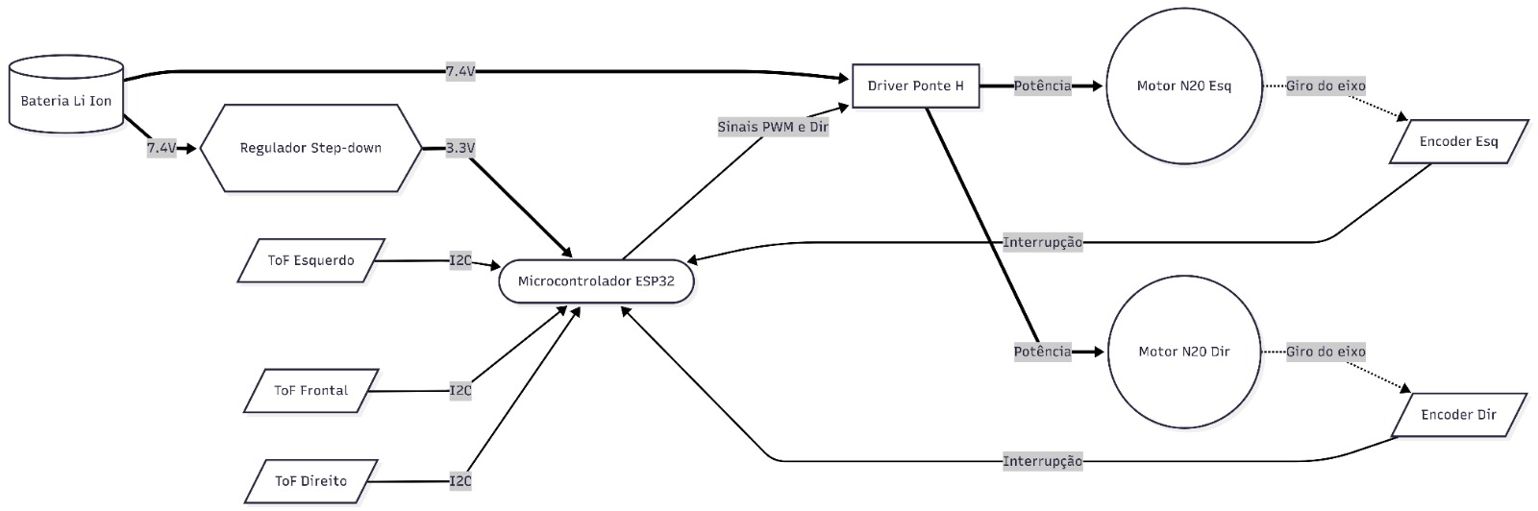
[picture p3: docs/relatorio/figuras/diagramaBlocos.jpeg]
    
    \caption{Diagrama de blocos do sistema.}
    \label{fig:diagrama-de-blocos}
\end{figure}

\subsection{Componentes eletrônicos}

\subsubsection{Microcontrolador}

O microcontrolador é o componente central do sistema embarcado do Micromouse.Eles consistem em pequenos sistemas computacionais integrados em um único chip, e contêm periféricos como memória RAM, memória Flash, interfaces de comunicação serial, conversores analógico-digitais e temporizadores \cite{chase_embarcados}.
    
Para a definição da plataforma utilizada no projeto, foi realizado um estudo comparativo entre os microcontroladores: Arduino Uno, STM32 e Raspberry Pi Pico. Após a análise, optou-se pela utilização do ESP32 DevKit WROOM devido ao seu elevado desempenho computacional, grande quantidade de periféricos integrados e suporte nativo à comunicação sem fio.

A ESP32 DevKit WROOM foi escolhida por possuir as seguintes caracteristicas: Arquitetura dual-core operando a até 240 MHz; permite dedicar um núcleo ao controle dos motores e leitura dos sensores, enquanto o outro executa os algoritmos de navegação e tomada de decisão; possui conectividade com rede Wi-fi; tem interface I²C para comunicação com sensores de distância; tem módulos PWM de alta resolução para acionamento dos motores e suporte a interrupções em múltiplos GPIOs.

%O ESP32 é um microcontrolador de alto desempenho desenvolvido para aplicações embarcadas que exigem conectividade, processamento e controle em tempo real\cite{esp32_datasheet}.Um dos principais diferenciais do ESP32 é sua arquitetura dual-core operando a até 240 MHz, permitindo a separação de tarefas críticas em diferentes núcleos de processamento. Dessa forma, é possível dedicar um núcleo ao controle dos motores e leitura dos sensores, enquanto o outro executa os algoritmos de navegação e tomada de decisão.
    
%Além disso, o ESP32 oferece periféricos fundamentais para o projeto, como interface I²C para comunicação com sensores de distância, módulos PWM de alta resolução para acionamento dos motores e suporte a interrupções em múltiplos GPIOs. Outro fator relevante é a conectividade Wi-Fi integrada, que possibilita futuras implementações de telemetria e monitoramento remoto.

%Dessa forma, o ESP32 apresentou a melhor relação entre desempenho, conectividade, flexibilidade e custo-benefício para atender aos requisitos do projeto.

\subsubsection{Sensores}

Os sensores de distância são componentes fundamentais para a navegação do Micromouse, uma vez que permitem a detecção de paredes e obstáculos no ambiente do labirinto sem a necessidade de contato físico. Para o projeto, foram analisadas as opçoes: sensores a laser ToF, ultrassônicos e infravermelhos.

%No contexto do projeto, os sensores de distância são responsáveis por fornecer informações em tempo real sobre a posição das paredes ao redor do robô, permitindo decisões rápidas de movimentação e correção de trajetória. Dessa forma, a escolha do tipo de sensor impacta diretamente na confiabilidade e desempenho do sistema de navegação.

Entre as tecnologias analisadas, os sensores do tipo Time-of-Flight (ToF), como o VL53L0X, destacam-se por sua alta precisão e baixo tempo de resposta, operando na ordem de milímetros. Além disso, sua medição não é significativamente afetada pela cor ou textura da superfície, o que os torna adequados para ambientes variados como labirintos. Já os sensores ultrassônicos apresentam maior alcance, porém possuem menor taxa de atualização e podem sofrer interferências devido à dispersão do sinal sonoro. Por outro lado, sensores infravermelhos são mais simples e de baixo custo, porém apresentam baixa precisão e forte dependência das condições ambientais.

Diante dessas características, o sistema do Micromouse utilizará sensores ToF como principal solução para detecção de obstáculos, posicionados nas direções frontal, esquerda e direita do robô, garantindo percepção espacial adequada para navegação no labirinto.

\subsubsection{Motores}

Segundo Chapman \cite{chapman_machines}, um motor elétrico é um dispositivo responsável por converter energia elétrica em energia mecânica, sendo amplamente utilizado em sistemas de automação e aplicações industriais. No contexto de sistemas embarcados e robótica móvel, como o Micromouse, os motores são responsáveis pela locomoção do robô, permitindo o controle preciso de movimento, direção e velocidade.

%O Micromouse é um robô autônomo que deve ser capaz de navegar em um ambiente de labirinto sem intervenção humana, utilizando sensores e algoritmos de controle para tomada de decisão. Dessa forma, o sistema de atuação mecânica, composto principalmente por motores DC, é um dos elementos mais críticos do projeto, pois influencia diretamente na precisão e estabilidade do movimento.

A escolha do motor GA12-N20-S0310D-E foi definida com base no equilíbrio entre torque, dimensões reduzidas e capacidade de controle fino. Ele possui uma caixa de redução integrada permite aumentar o torque disponível na saída, o que é essencial para garantir movimentação eficiente do robô durante acelerações, desacelerações e mudanças bruscas de direção, comuns em ambientes de labirinto.

Além disso, o motor selecionado possui encoder acoplado ao eixo, permitindo a medição da rotação e, consequentemente, do deslocamento das rodas. Essa característica é fundamental para o sistema de odometria do Micromouse, possibilitando estimar a posição do robô ao longo do percurso e auxiliar na correção de trajetória durante a navegação.

Outro fator relevante é o seu tamanho compacto, que facilita a integração mecânica em um chassi com restrição de espaço. Em comparação com motores DC convencionais, o modelo N20 oferece maior precisão de controle e maior confiabilidade na leitura de movimento. Além disso, quando comparado a motores de passo, apresenta melhor eficiência energética e maior velocidade de resposta, características importantes para aplicações de robótica móvel de pequeno porte.

\subsubsection{Conversor DC-DC Buck (LM2596)}

O conversor DC-DC do tipo Buck é um circuito eletrônico responsável pela redução de tensão contínua com alta eficiência energética, sendo amplamente utilizado em sistemas embarcados que exigem múltiplos níveis de alimentação. De acordo com Erickson e Maksimović \cite{erickson_power_electronics}, conversores chaveados como o Buck operam por meio de comutação de alta frequência, permitindo a conversão de energia com baixas perdas em comparação a reguladores lineares.

No contexto do Micromouse, a regulação de tensão é um elemento crítico, uma vez que o sistema é composto por diferentes subsistemas que operam em níveis distintos de tensão. Dessa forma, são utilizados no projeto dois conversores: um de 5V para alimentar a ESP32 e o outro de 6V para alimentar o motor.

O conversor LM2596 foi selecionado para o projeto devido à sua ampla utilização em aplicações embarcadas, capacidade de fornecer correntes elevadas e alta eficiência de conversão. Além disso, o módulo permite ajuste da tensão de saída, o que facilita a adaptação para diferentes cargas dentro do sistema.

Dessa forma, o conversor DC-DC LM2596 desempenha um papel essencial na arquitetura eletrônica do Micromouse, garantindo a correta distribuição de energia entre os diferentes módulos do sistema.

\subsubsection{Driver de Motores TB6612FNG}

O driver de motores é um componente essencial em sistemas embarcados que utilizam motores DC, sendo responsável por atuar como interface entre o microcontrolador e o sistema de potência dos motores. Microcontroladores não são capazes de fornecer corrente suficiente para acionamento direto de motores, sendo necessário o uso de circuitos intermediários capazes de amplificar corrente e controlar o sentido de rotação.

No contexto do Micromouse, o driver TB6612FNG é utilizado para controlar dois motores DC de forma independente, permitindo o controle de direção e velocidade por meio de sinais PWM e entradas lógicas de direção. Esse componente é fundamental para garantir o controle preciso da locomoção do robô durante a navegação no labirinto.

O TB6612FNG se destaca por sua alta eficiência energética. Além disso, o driver suporta corrente contínua, sendo adequado para motores de pequeno porte utilizados em robótica móvel. Dessa forma, o TB6612FNG foi selecionado por oferecer um bom equilíbrio entre eficiência, tamanho compacto e capacidade de controle, atendendo aos requisitos do sistema embarcado do Micromouse.

\subsection{Comunicação e GPIOs}

% Todo o controle dos motores e informações vindas dos sensores sera feito pelos pinos de proposito geral da esp32 os GPIOs, os sensores de distancia ToF (Time-Of-Flight) serão gerenciados como input nos GPIOs respectivos para comunicação serial I2C \cite{i2cbus_specification} e a partir das informações dos sensores de distancia e da entrada dos encoders a partir de leitura digital basica, executaremos as tomadas de decisões especificadas no software para controlar os motores a partir de escrita digital basica e pwm através da ponte H

O controle dos motores e o gerenciamento das informações dos sensores serão realizados por meio dos pinos de propósito geral da ESP32 (GPIOs). Os sensores de distância ToF (\textit{Time-of-Flight}) serão conectados à ESP32 por meio do barramento de comunicação serial I2C, utilizando os pinos GPIO configurados para as linhas SDA e SCL \cite{i2cbus_specification}. Dessa forma, os dados de distância obtidos pelos sensores poderão ser utilizados pelo software embarcado para a tomada de decisões durante a navegação do robô.

Além disso, os sinais provenientes dos encoders serão lidos por entradas digitais da ESP32, permitindo estimar o deslocamento e o sentido de rotação dos motores. Com base nas informações dos sensores ToF e dos encoders, o sistema de controle executará as decisões definidas no software, acionando os motores por meio de sinais digitais e sinais PWM enviados à ponte H.

\subsection{Esquemático do Circuito}

% O esquema eletrico foi desenvolvido com o intuito de integrar os sensores, motores o driver dos motores e o microcontrolador escolhido a Esp32 e a bateria, para avaliar a interligação entre os componentes e avaliar a necessidade de sistemas auxiliares como os buck's para regular a tensão da bateria para entrar nos componentes com a tensão certa.

O esquema elétrico foi desenvolvido para representar a integração entre os sensores, os motores, o driver de acionamento, o microcontrolador ESP32 e a bateria. A partir dele, é possível analisar como os componentes se conectam entre si e verificar a necessidade de elementos auxiliares, como conversores buck, utilizados para ajustar a tensão da bateria aos valores adequados para cada parte do circuito.

\begin{figure}[htpb]
    \centering
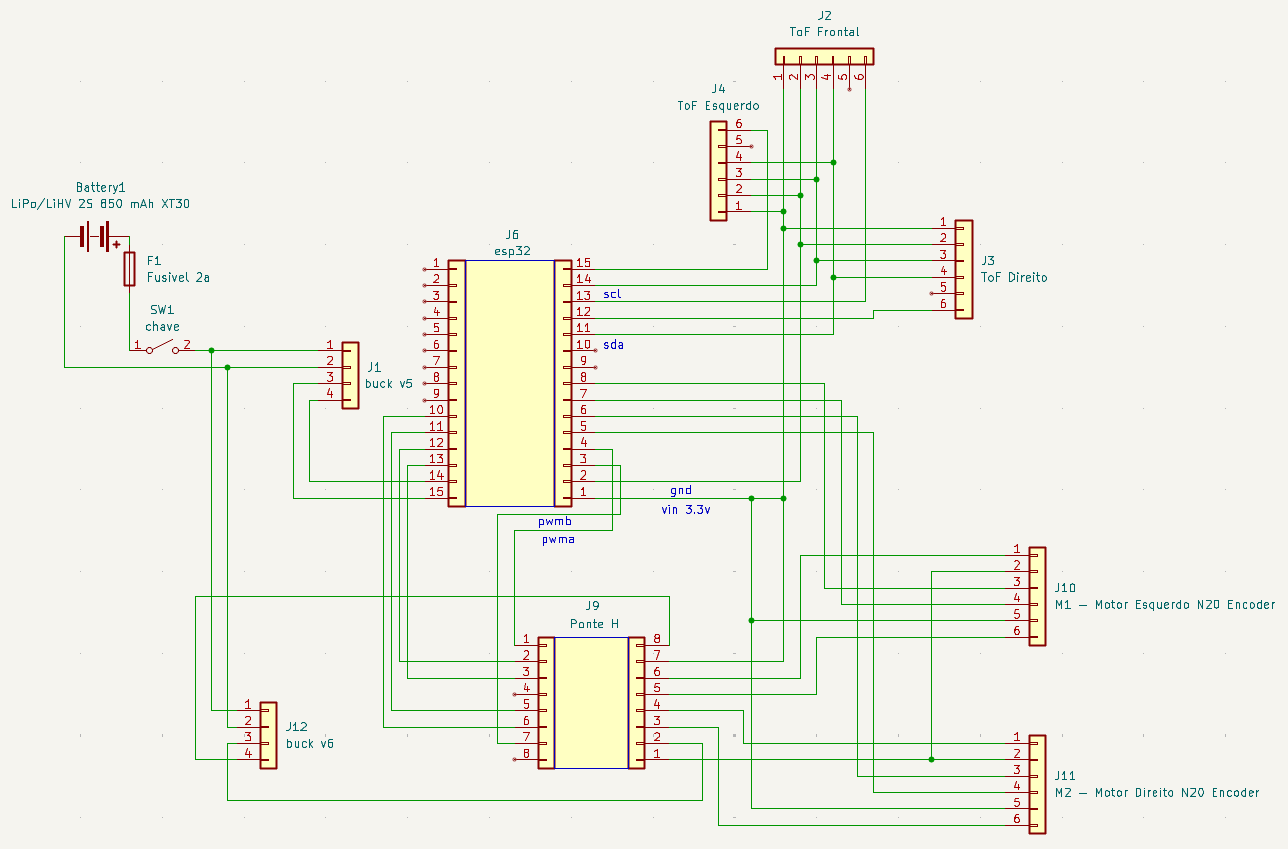
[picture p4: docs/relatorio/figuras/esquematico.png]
    
    \caption{Esquema elétrico do sistema.}
    \label{fig:esquema-eletrico}
\end{figure}

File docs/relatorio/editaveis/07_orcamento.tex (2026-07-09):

\begin{landscape}

\chapter{Orçamento}
\label{orca}

\begin{table}[htpb]
\begin{center}
\caption{Orçamento geral.}
\begin{tabular}{|l|c|c|}
\hline
\textbf{Geral}          & \textbf{Previsto (R\$)} & \textbf{Realizado (R\$)} \\ \hline
Matéria-prima           & 92,00                    & 210,43                     \\ \hline
Componentes eletrônicos & 327,51                    & 622,54                     \\ \hline
Componentes elétricos   & 225,63                  &  200,72                \\ \hline
Ferramentas             & 0                    & 0                     \\ \hline
Montagem                & 89,00                    & 209,00                     \\ \hline
\end{tabular}
\end{center}
\end{table}

\newpage

\begin{table}[htpb]
\begin{center}
\caption{Orçamento por aquisição.}
\begin{tabular}{|l|c|c|c|c|}
\hline
\textbf{Item ou serviço} & \textbf{Tipo} & \textbf{Previsto (R\$)} & \textbf{Realizado (R\$)} & \textbf{Responsável} \\ \hline
Pack de bateria Li-Ion 7,4V 2500mAh ( 1 unid.)
& Componente elétrico & 95,22 & 67,51 & Ana Luiza \\ \hline

Mini carregador para bateria de lítio 2S (1 unid.)
& Componente elétrico & 65,23 & 46,24 & Ana Luiza \\ \hline

Fonte chaveada 9V 1A ( 1 unid.)
& Componente elétrico & 39,24 & 27,82 & Ana Luiza \\ \hline

Conector JST RCY macho/fêmea com fio (1 unid.)
& Componente elétrico & 17,99 & 17,99 & Ana Luiza \\ \hline

Sensor de corrente DC INA219 I2C (1 unid.)
& Componente eletrônico & 34,40 & 33,43 & Ana Luiza \\ \hline

Motor GA12 N20 DC com Encoder (2 unid.)
& Componente eletrônico & 104,10 & 104,10 & José Vinícius \\ \hline

ESP32 DEVKit (1 unid.)
& Componente eletrônico & 55,90 & 55,90 & Maurício Ferreira \\ \hline

Protoboard 400 pontos (1 unid.)
& Componente eletrônico & 36,90 & 36,90 & Maurício Ferreira \\ \hline

componentes eletrônicos excedentes
& Componente eletrônico & 00,00 & 213,00 & Maurício Ferreira \\ \hline

Ponte H ( 1 unid.)
& Componente eletrônico & 51,90 & 33,90 & Júlia Fortunato \\ \hline

Bucks reguladores de tensão ( 2 unid.)
& Componente eletrônico & 23,99 & 23,99 & Ana Luiza \\ \hline

Sensor ToF ( 3 unid.)
& Componente eletrônico & 20,32 & 20,32 & José Vinícius \\ \hline

jumpers macho-macho (40 unid.)
& Componente elétrico & 7,95 & 7,73 & Ana Luiza \\ \hline

MDF de 15 mm de espessura (1 unid. de 720x720mm) & Matéria-prima & 70,00 & 36,00 & Bianca Zero \\ \hline

EVA alta densidade (40 unid. de 180 x 50 x 12 mm) & Matéria-prima & 56,00 & 56,00 & Bianca Zero \\ \hline

Palitos de picolé com borda quadrada (80 unid.) & Montagem & 18,00 & 18,00 & Bianca Zero \\ \hline

Suporte em L (160 unid.) & Montagem & 46,00 & 46,00 & Bianca Zero \\ \hline

Impressão 3D do chassi, laterais, rodas e engrenagens & Montagem & 25,00 & 25,00 & Bianca Zero \\ \hline

Impressão segundo chassi e engranagem & Montagem & 35,00 & 35,00 & Ana Luiza Soares \\ \hline

Rolamentos & Matéria-prima & 58,90 & 58,90 & Bianca Zero \\ \hline

Parafusos & Matéria-prima & 7,00 & 7,00 & Bianca Zero \\ \hline

Terceira impressão & Montagem & 50,00 & 50,00 & Bianca Zero \\ \hline

Rolamentos & Matéria-prima & 58,90 & 58,90 & Bianca Zero \\ \hline

Aneis O-rings & Matéria-prima & 29,26 & 29,26 & Bianca Zero \\ \hline

\end{tabular}
\end{center}
\end{table}

\end{landscape}

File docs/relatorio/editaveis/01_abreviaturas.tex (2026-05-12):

\begin{siglas}
  \item[ESP32] Microcontrolador da Espressif Systems
  \item[RAM] Random Access Memory
  \item[USB] Universal Serial Bus
  \item[TCP/IP] Transmission Control Protocol / Internet Protocol
  \item[PWM] Pulse Width Modulation
  \item[I\textsuperscript{2}C] Inter-Integrated Circuit
  \item[GPIO] General Purpose Input/Output
  \item[ToF] Time of Flight
  \item[unid] Unidade
  \item[UnB] Universidade de Brasília
  \item[FCTE] Faculdade de Ciências e Tecnologias em Engenharia
  \item[PI1] Projeto Integrador de Engenharia 1
  \item[IEEE] Institute of Electrical and Electronics Engineers
  \item[CAD] Computer-Aided Design
  \item[EAP] Estrutura Analítica do Projeto
  \item[UML] Unified Modeling Language
  \item[DFS] Depth-First Search
  \item[PID] Proportional-Integral-Derivative
  \item[FSM] Finite State Machine
  \item[UDP] User Datagram Protocol
  \item[Wi-Fi] Wireless Fidelity
  \item[BMS] Battery Management System
  \item[DC] Direct Current
  \item[ADC] Analog-to-Digital Converter
  \item[MDF] Medium-Density Fiberboard
  \item[EVA] Ethylene Vinyl Acetate
  \item[PLA] Polylactic Acid
  \item[IMU] Inertial Measurement Unit
  \item[HU] História de Usuário
  \item[RF] Requisito Funcional
  \item[RNF] Requisito Não Funcional
  \item[MVC] Model-View-Controller
  \item[CSV] Comma-Separated Values
  \item[JSON] JavaScript Object Notation
  \item[TSDB] Time Series Database
  \item[MoSCoW] Must have, Should have, Could have, Won't have
  \item[BOM] Bill of Materials
  \item[FGA] Faculdade do Gama
  \item[CG] Centro de Gravidade
  \item[SI] Sistema Internacional
  \item[SDA] Serial Data Line
  \item[SCL] Serial Clock Line
  \item[LittleFS] Little File System
  \item[SDMMC] SD/MMC Interface
  \item[CSS] Cascading Style Sheets
  \item[UP] Processo Unificado
  \item[TF] Teste Funcional
  \item[FGA] Faculdade UnB Gama
\end{siglas}

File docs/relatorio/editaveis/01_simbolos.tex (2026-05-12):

\begin{simbolos}
  \item[$\Gamma$] Letra grega Gama
  \item[$\Lambda$] Lambda
  \item[$\zeta$] Letra grega minúscula zeta
  \item[$\in$] Pertence
  \item[$\leq$] Menor ou igual que
  \item[$\mu$] Letra grega Mu minúscula
  \item[$\geq$] Maior ou igual que
  \item[$\theta$] Letra grega Theta
  \item[$\rightarrow$] Seta para a direita
  \item[$F_t$] Força trativa
  \item[$F_{rr}$] Força de resistência ao rolamento
  \item[$C_{rr}$] Coeficiente de resistência ao rolamento
  \item[$b$] Coeficiente de atrito de rolamento
  \item[$R$] Raio da roda
  \item[$m$] Massa do robô
  \item[$g$] Aceleração da gravidade
  \item[$T_{min}$] Torque mínimo requerido
  \item[$T_{proj}$] Torque de projeto com margem de segurança
  \item[$a$] Aceleração linear
  \item[$\tau$] Torque
  \item[$\mu_e$] Coeficiente de atrito estático
  \item[$h_{max}$] Altura máxima do centro de gravidade
  \item[$L$] Comprimento da base do robô
  \item[$x$] Distância horizontal do centro de gravidade ao eixo frontal
  \item[$E_J$] Energia consumida em joules
  \item[$E_{Wh}$] Energia consumida em watt-hora
  \item[$V$] Tensão elétrica em volts
  \item[$I$] Corrente elétrica em amperes
  \item[$t$] Tempo de operação em segundos
  \item[$P_{media}$] Potência média consumida pelo sistema
  \item[$E_{util}$] Energia útil disponível da bateria
\end{simbolos}

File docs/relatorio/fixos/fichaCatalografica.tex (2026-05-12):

\begin{fichacatalografica}
	\vspace*{\fill}					% Posição vertical
	\hrule							% Linha horizontal
	\begin{center}					% Minipage Centralizado
	\begin{minipage}[c]{12.5cm}		% Largura
	
	\imprimirautor
	
	\hspace{0.5cm} \imprimirtitulo  / \imprimirautor. --
	\imprimirlocal, \imprimirdata-
	
	\hspace{0.5cm} \pageref{LastPage} p. : il. (algumas color.) ; 30 cm.\\
	
	\hspace{0.5cm} \imprimirorientadorRotulo~\imprimirorientador\\
	
	\hspace{0.5cm}
	\parbox[t]{\textwidth}{\imprimirtipotrabalho~--~\imprimirinstituicao,
	\imprimirdata.}\\
	
	\hspace{0.5cm}
		1. \imprimirpalavrachaveum.
		2. \imprimirpalavrachavedois.
		I. \imprimirorientador.
		II. Universidade de Brasília.
		III. Faculdade de Ciências e Tecnologias em Engenharia.
		IV. \imprimirtitulo\\ 			
	
	\hspace{8.75cm} CDU \\ %\nomecdu\\
	
	\end{minipage}
	\end{center}
	\hrule
        \pagebreak
\end{fichacatalografica}

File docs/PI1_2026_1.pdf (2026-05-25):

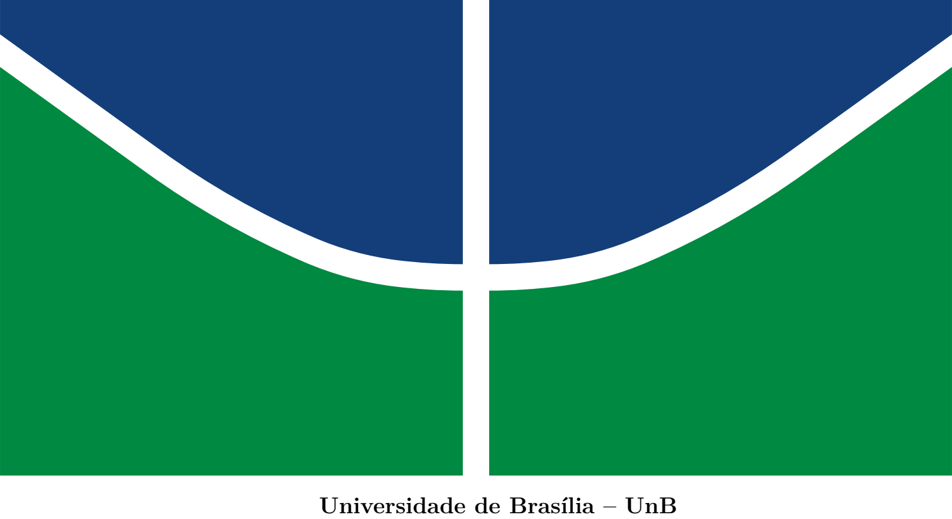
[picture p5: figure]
Universidade de Brasília – UnB

Faculdade de Ciências e Tecnologias em Engenharia – FCTE

## Projeto de PI1 - ED1

Autor: Alexandre Alvarez, Ana Luiza Soares, Arthur da Paixão, Arthur Ribeiro, Bianca Zero, Caio Bechepeche, Caio Borges, Carlos Paz, Gabriel Vale, Ian Guimarães, João Victor Santos, José de Queiroz, Júlia Fortunato, Maurício Araújo, Renan Castro, Renato Filho, Ruan Prado, Sahuan Melo, Yzabella Pimenta

Orientador: Prof. Lui Txai Calvoso Habl

Brasília, DF

2026

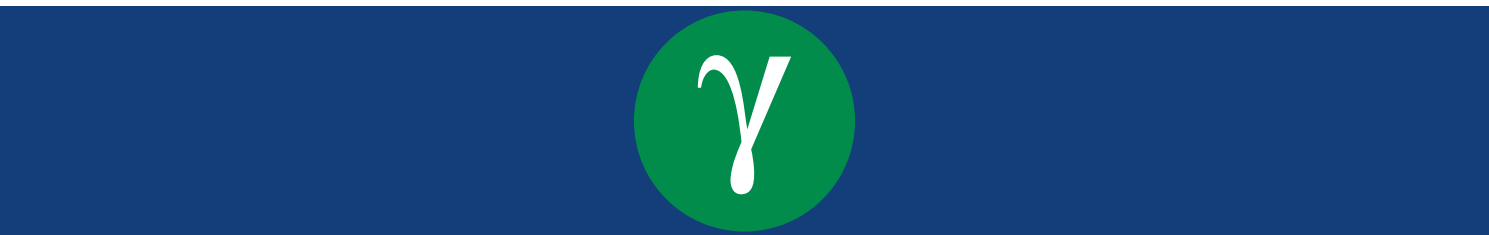
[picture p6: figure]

Alexandre Alvarez, Ana Luiza Soares, Arthur da Paixão, Arthur Ribeiro, Bianca Zero, Caio Bechepeche, Caio Borges, Carlos Paz, Gabriel Vale, Ian Guimarães, João Victor Santos, José de Queiroz, Júlia Fortunato, Maurício Araújo, Renan Castro, Renato Filho, Ruan Prado, Sahuan Melo, Yzabella Pimenta

## Projeto de PI1 - ED1

Trabalho submetido à disciplina de Projeto Integrador de Engenharia 1 da Universidade de Brasília.

Universidade de Brasília – UnB

Faculdade de Ciências e Tecnologias em Engenharia – FCTE

### Orientador: Prof. Lui Txai Calvoso Habl

### Coorientador: Prof. Diogo Caetano Garcia, Profa. Juliana Petrocchi Rodrigues Prof. Hilmer Rodrigues Neri, e Prof. Bruno Luiz Pereira

### Brasília, DF

2026

Alexandre Alvarez, Ana Luiza Soares, Arthur da Paixão, Arthur Ribeiro, Bianca Zero, Caio Bechepeche, Caio Borges, Carlos Paz, Gabriel Vale, Ian Guimarães, João Victor Santos, José de Queiroz, Júlia Fortunato, Maurício Araújo, Renan Castro, Renato Filho, Ruan Prado, Sahuan Melo, Yzabella Pimenta
Projeto de PI1 - ED1/ Alexandre Alvarez, Ana Luiza Soares, Arthur da Paixão, Arthur Ribeiro, Bianca Zero, Caio Bechepeche, Caio Borges, Carlos Paz, Gabriel Vale, Ian Guimarães, João Victor Santos, José de Queiroz, Júlia Fortunato, Maurício Araújo, Renan Castro, Renato Filho, Ruan Prado, Sahuan Melo, Yzabella Pimenta. – Brasília, DF, 2026-
60 p. : il. (algumas color.) ; 30 cm.

Orientador: Prof. Lui Txai Calvoso Habl

Projeto Integrador de Engenharia 1 – Universidade de Brasília – UnB Faculdade de Ciências e Tecnologias em Engenharia – FCTE , 2026.
1. Projeto Integrador de Engenharia 1. 2. Faculdade UnB Gama - FCTE.
I. Prof. Lui Txai Calvoso Habl. II. Universidade de Brasília. III. Faculdade de Ciências e Tecnologias em Engenharia. IV. Projeto de PI1 - ED1

CDU

# Resumo

Este projeto tem como objetivo desenvolver uma interface web para monitoramento e controle de um robô autônomo navegando em labirintos, oferecendo ao operador a visualização em tempo real das leituras dos sensores Time of Flight (ToF) frontais e laterais, com auditoria da precisão na detecção de paredes. Entre os principais requisitos funcionais, destacam-se a autenticação segura de operadores por meio de tela de login com validação de credenciais e controle de sessão; a exibição dinâmica das paredes detectadas na matriz visual assim que os valores brutos dos sensores estabilizarem abaixo do limiar configurado; e a comunicação eficiente entre o frontend e o firmware do robô para recebimento contínuo dos dados de distância. O projeto foi desenvolvido no contexto do Projeto Integrador de Engenharia 1 da Faculdade UnB Gama – FCTE, consolidando conhecimentos de programação web, usabilidade e sistemas embarcados em uma aplicação prática de robótica móvel.

Palavras-chave: Projeto Integrador de Engenharia 1. Faculdade UnB Gama – FCTE. Robótica Móvel. Interface Web. Sensores ToF.

# Lista de ilustrações

Figura 8 – Desenho esquemático do labirinto de testes com o posicionamento dos

Figura 10 – Vista explodida do Micromouse com hierarquia de montagem e a inte-

Figura 11 – Renderização isométrica do modelo CAD detalhando a disposição mo-

# Lista de tabelas

Tabela 5 – Consumo energético individual dos componentes em 18 minutos . . . . 30

Tabela 7 – Capacidade mínima sem considerar a profundidade de descarga . . . . 31 Tabela 8 – Capacidade mínima corrigida considerando a capacidade útil da bateria 31 Tabela 9 – Modelagem de Dados no InfluxDB (Measurement: log_corrida) . . . 39

Tabela 15 – Listagem integral dos Requisitos Funcionais (RF) e Não-Funcionais

Tabela 16 – Roteiro de validação funcional do sistema de telemetria e dashboard. . 54

# Lista de abreviaturas e siglas

ESP32 | Microcontrolador da Espressif Systems
RAM | Random Access Memory
USB | Universal Serial Bus
TCP/IP | Transmission Control Protocol / Internet Protocol
PWM | Pulse Width Modulation

I

2C | Inter-Integrated Circuit
GPIO | General Purpose Input/Output
ToF | Time of Flight
unid | Unidade
UnB | Universidade de Brasília
FCTE | Faculdade de Ciências e Tecnologias em Engenharia
PI1 | Projeto Integrador de Engenharia 1
IEEE | Institute of Electrical and Electronics Engineers
CAD | Computer-Aided Design
EAP | Estrutura Analítica do Projeto
UML | Unified Modeling Language
DFS | Depth-First Search
PID | Proportional-Integral-Derivative
FSM | Finite State Machine
UDP | User Datagram Protocol
Wi-Fi | Wireless Fidelity
BMS | Battery Management System
DC | Direct Current

ADC | Analog-to-Digital Converter
MDF | Medium-Density Fiberboard
EVA | Ethylene Vinyl Acetate
PLA | Polylactic Acid
IMU | Inertial Measurement Unit
HU | História de Usuário
RF | Requisito Funcional
RNF | Requisito Não Funcional
MVC | Model-View-Controller
CSV | Comma-Separated Values
JSON | JavaScript Object Notation
TSDB | Time Series Database
MoSCoW | Must have, Should have, Could have, Won’t have
BOM | Bill of Materials
FGA | Faculdade do Gama
CG | Centro de Gravidade
SI | Sistema Internacional
SDA | Serial Data Line
SCL | Serial Clock Line
LittleFS | Little File System
SDMMC | SD/MMC Interface
CSS | Cascading Style Sheets
UP | Processo Unificado
TF | Teste Funcional
FGA | Faculdade UnB Gama

# Lista de símbolos

Γ | Letra grega Gama
Λ | Lambda
ζ | Letra grega minúscula zeta
∈ | Pertence
≤ | Menor ou igual que
μ | Letra grega Mu minúscula
≥ | Maior ou igual que
θ | Letra grega Theta
→ | Seta para a direita
Ft | Força trativa
Frr | Força de resistência ao rolamento
Crr | Coeficiente de resistência ao rolamento
b | Coeficiente de atrito de rolamento
R | Raio da roda
m | Massa do robô
g | Aceleração da gravidade
Tmin | Torque mínimo requerido
Tproj | Torque de projeto com margem de segurança
a | Aceleração linear
τ | Torque
μe | Coeficiente de atrito estático
ℎmax | Altura máxima do centro de gravidade
L | Comprimento da base do robô

x | Distância horizontal do centro de gravidade ao eixo frontal
EJ | Energia consumida em joules
EW ℎ | Energia consumida em watt-hora
V | Tensão elétrica em volts
I | Corrente elétrica em amperes
t | Tempo de operação em segundos
Pmedia | Potência média consumida pelo sistema
Eutil | Energia útil disponível da bateria

# Sumário

APÊNDICES | 51

13

# 1 Introdução

O Micromouse é uma competição de robótica móvel autônoma na qual um pequeno robô deve percorrer um labirinto desconhecido e alcançar uma região-alvo, geralmente localizada no centro do labirinto, no menor tempo possível. A proposta surgiu no contexto da competição Amazing MicroMouse Maze Contest, que foi idealizada pela IEEE Spectrum, na qual os robôs deveriam possuir lógica e memória próprias para explorar o labirinto, aprender com tentativas anteriores e melhorar o desempenho em uma corrida final (CHRISTIANSEN, 2014). Desde então, o desafio tornou-se uma atividade recorrente em eventos acadêmicos e competições de robótica, passando a ser como plataforma para o estudo de navegação autônoma, planejamento de trajetórias, sensoriamento, controle de motores e integração de sistemas embarcados (MILOS et al., 2010).

De acordo com regras tradicionais da modalidade, o labirinto padrão do Micromouse é composto por uma matriz de células, comumente organizada em uma grade de 16 × 16, em que cada célula possui dimensões de 18 × 18 cm. As paredes possuem aproximadamente 5 cm de altura e 1,2 cm de espessura, enquanto o robô não deve exceder 25 cm de comprimento ou largura (IEEE-RHU, 2024). Além disso, o robô deve operar sem intervenção humana durante a execução, ou seja, não sendo possível receber informações externas sobre a configuração do labirinto após o início da prova. No contexto deste projeto, proposto pela disciplina de PI1, o micromouse deverá alcançar zonas em três labirintos desconhecidos, com dimensões de 4×4, 8×8 e 16×16 células, respeitando as restrições físicas e operacionais propostas para a competição (GARCIA et al., 2026).

O desenvolvimento de um Micromouse envolve a integração de diferentes áreas da engenharia. Milos et al. (MILOS et al., 2010) descrevem esse tipo de projeto como uma atividade interdisciplinar, na qual conhecimentos de diferentes áreass, como ciência da computação, engenharia de computação, engenharia elétrica e engenharia mecânica são aplicados conjuntamente para transformar conceitos teóricos em um sistema físico funcional. Essa característica também está presente no presente projeto, que demanda a concepção da estrutura mecânica do robô, a seleção de sensores e atuadores, o desenvolvimento do circuito eletrônico, a programação embarcada, o controle de movimento e a implementação de um sistema de visualização e armazenamento dos dados obtidos durante a execução, abrangendo todos os cursos de Engenharia da FCTE.

Assim, o desenvolvimento do Micromouse é justificado, nesse contexto, como uma solução educacional e tecnológica capaz de reunir, em um único produto, conceitos de robótica móvel, sistemas embarcados, eletrônica, controle, programação, banco de dados e desenvolvimento web. O produto proposto não se limita à construção de um robô que

Capítulo 1. Introdução | 14

percorre labirintos, pois também inclui a exibição em tempo real de dados de telemetria, como tipo de labirinto, trajeto percorrido, consumo de bateria, velocidade média, tempo de conclusão e indicação de cumprimento do desafio, além do armazenamento dos resultados finais para consultas posteriores (GARCIA et al., 2026). Com isso, o projeto atende às necessidades da disciplina ao propor um sistema próprio, verificável e interdisciplinar, permitindo avaliar tanto o desempenho físico do robô quanto a qualidade das informações geradas durante sua operação.

O trabalho presente neste documento está estuturado da seguinte forma: o capítulo 2 apresenta o termo de abertura, com informações importantes para o projeto; a equipe de trabalho, e a avaliação de desempenho dos memebros, é apresentada no capítulo 3; o capítulo 4 apresenta o projeto conceitual do produto, que define as características das quatros áreas presentes no projeto (Estrutura, Energia, Eletrônica e Software), bem como a integração entre elas. No capítulo 5, é apresentado o orçamento do projeto; e o cronograma é documentado no capítulo 6. Por fim, o capítulo 7 apresenta a síntese do documento.

15

# 2 Termo de Abertura do Projeto

## 2.1 Dados do projeto

Nome do Projeto: Micromouse

Data de abertura: 05/05/2026

Código: 1-A

Patrocinador: Universidade de Brasília

Gerente: Ian Costa Guimarães/222014859/iancostag@gmail.com/6199299-8915

## 2.2 Objetivos

O objetivo central é projetar, construir e programar um robô móvel autônomo capaz de mapear e resolver labirintos de 4x4, 8x8 e 16x16 células, integrando-o a uma plataforma web para telemtria. Seguindo a regra SMART:

Specific (específico): Desenvolver um robô físico (Micromouse) que resolva 3 labirintos distintos de forma autônoma e um sistema web para visualização de telemetria (trajeto, velocidade e bateria) em tempo real.

Measurable (mensurável): O sucesso será medido pela conclusão dos labirintos de até 16x16 células e pela recepção de pacotes de dados via UDP/WebSockets com latência inferior a 50ms.

Agreed (acordado): O projeto foi validado pelos líderes das quatro áreas (Software, Eletrônica, Energia e Estruturas) e pelo gerente geral, garantindo a integração dos subsistemas.

Realistic (realista): O projeto utiliza tecnologias acessíveis e consolidadas (ESP32, Motores N20, Sensores ToF) compatíveis com o orçamento e o laboratório de eletrônica da FGA.

Time Bound (limitado no tempo): A entrega final do protótipo funcional e do relatório técnico completo (ED1) está definida para 11 de maio de 2026.

Capítulo 2. Termo de Abertura do Projeto | 16

## 2.3 Mercado-alvo

O projeto destina-se a instituições acadêmicas e de pesquisa em robótica móvel, além de competições tecnológicas promovidas pelo IEEE. Internamente, atende aos requisitos pedagógicos da disciplina de Projeto Integrador de Engenharia 1 da Faculdade de Ciências e Tecnologias em Engenharia (FCTE-UnB), servindo como plataforma de estudo para estudantes de Engenharia de Software, Eletrônica, Energia, Aeroespacial e Automotiva, promovendo entendimento holístico de um projeto de engenharia muldisciplinar real.

## 2.4 Requisitos

Os requisitos essenciais para a viabilidade do produto incluem:

- Dimensões Operacionais: O robô deve possuir largura entre 7cm e 10cm para navegar livremente em corredores de 16,8cm.
- Processamento: Utilização de microcontrolador dual-core (ESP32) para processamento paralelo de controle e telemetria.
- Navegação: Sensores de distância do tipo Time-of-Flight (VL53L0X) para mapeamento preciso e independente da cor das superfícies.
- Monitoramento: Dashboard web responsivo que exiba a posição do robô em tempo real via Wi-Fi.
- Autonomia: Sistema de energia capaz de alimentar motores e comunicação sem fio durante o ciclo completo de resolução de 3 labirintos.

## 2.5 Justificativa

O desenvolvimento do projeto Micromouse é justificado pela necessidade de integrar, em um único sistema, conhecimentos multidisciplinares das diferentes engenharias da Faculdade de Ciências e Tecnologias em Engenharia (FCTE-UnB). O projeto permite aplicar conceitos de sistemas embarcados, eletrônica, controle, programação, mecânica, banco de dados e desenvolvimento web em um contexto prático e competitivo, aproximando os estudantes de problemas reais de engenharia.

Além do caráter acadêmico, o projeto atende à crescente demanda por soluções autônomas capazes de realizar navegação inteligente em ambientes desconhecidos. Tecnologias semelhantes às utilizadas em competições Micromouse também estão presentes em aplicações industriais, robótica móvel, logística automatizada e veículos autônomos,

Capítulo 2. Termo de Abertura do Projeto | 17

tornando o projeto relevante como ferramenta de capacitação técnica e desenvolvimento profissional.

Outro fator que justifica o projeto é a oportunidade de desenvolver uma plataforma de monitoramento em tempo real integrada ao robô, que permite acompanhar métricas de desempenho, telemetria e comportamento do sistema durante a execução das tarefas. Essa funcionalidade amplia o potencial educacional do projeto, possibilitando análises posteriores, validação experimental e apoio ao processo de tomada de decisão durante os testes.

No contexto da disciplina de Projeto Integrador de Engenharia 1, o Micromouse também contribui para o desenvolvimento de competências relacionadas à gestão de projetos, trabalho em equipe, rastreabilidade de atividades, documentação técnica e integração entre áreas, competências fundamentais para a formação de engenheiros.

## 2.6 Indicadores

Os indicadores definidos para o projeto têm como objetivo medir o desempenho técnico do sistema desenvolvido, bem como avaliar sua aderência aos requisitos estabelecidos para a competição e para a disciplina. Os principais indicadores considerados são:

- Taxa de sucesso na resolução dos labirintos de 4x4, 8x8 e 16x16 células;
- Tempo médio necessário para completar o percurso até a região objetivo;
- Latência média da transmissão de telemetria entre o robô e o dashboard web;
- Precisão do mapeamento do labirinto realizado pelo algoritmo de navegação;
- Número de colisões ou falhas de navegação durante os testes;
- Autonomia energética do sistema durante as execuções consecutivas;
- Taxa de perda de pacotes de telemetria durante a comunicação Wi-Fi;
- Velocidade média de deslocamento do robô durante a exploração;
- Quantidade de requisitos funcionais implementados e validados nos testes;
- Percentual de atividades concluídas dentro do prazo planejado no GitHub Projects.

18

# 3 Equipe de Trabalho

Tabela 1 – Composição da equipe.

Nome | Matrícula | Curso | Telefone | E-mail | Atribuições
Alexandre Macedo Alvarez | 24/2028619 | Eng. de Software | (11) 91475-7052 | 242028619@aluno.unb.br | Estruturas
Ana Luiza Soares de Carvalho | 23/1011088 | Eng. de Software | (61) 99346-8282 | 221022088@aluno.unb.br | Gerente de área - Energia
Arthur Augusto Rezende da Paixão | 21/1031600 | Eng. de Software | (61) 98621-4983 | 211031600@aluno.unb.br | Eletrônica
Arthur Mateus Ribeiro | 24/2015423 | Eng. Automotiva | (61) 99961-4897 | 242015423@aluno.unb.br | Estruturas
Bianca Gonçalves Zero | 23/1011140 | Eng. Aeroespacial | (61) 98326-2792 | 231011140@aluno.unb.br | Gerente de área - Estruturas
Caio Bechepeche Mota | 24/2042340 | Eng. de Software | (61) 98339-2680 | 242042340@aluno.unb.br | Eletrônica
Caio Melo Borges | 21/1030952 | Eng. de Software | (61) 98638-9899 | 211030952@aluno.unb.br | Software
Carlos Eduardo de Sousa Paz | 22/2022064 | Eng. de Software | (61) 99273-2974 | 222022064@aluno.unb.br | Software
Ian Costa Guimarães | 22/2014859 | Eng. de Software | (61) 99299-8915 | 222014859@aluno.unb.br | Gerente - Software
João Victor Pires Sapiência Santos | 23/1026400 | Eng. de Software | (62) 98531-0036 | 231026400@aluno.unb.br | Eletrônica
José Vinicius Alvares Soares de Queiroz | 22/2006884 | Eng. de Software | (61) 98194-3094 | 222006884@aluno.unb.br | Eletrônica
Júlia Rocha Fortunato | 22/1022355 | Eng. de Software | (61) 98192-4513 | 221022355@aluno.unb.br | Sub-Gerente - Energia
Maurício Ferreira de Araújo | 22/2007021 | Gerente de área - Eletrônica | (61) 9924-0047 | 222007021@aluno.unb.br | Eletrônica
Renan Curione de Castro | 24/2024834 | Eng. de Software | (61) 8383-8660 | 242024834@aluno.unb.br | Software
Renato Rodrigues Campos Filho | 24/2015933 | Eng. de Software | (61) 9646-3170 | 242015933@aluno.unb.br | Eletrônica
Ruan Apostolo Prado | 24/2015414 | Eng. Aeroespacial | (61) 9117-2546 | 242015414@aluno.unb.br | Estruturas
Sahuan Ferreira Melo | 24/2024023 | Eng. de Software | (61) 8533-8427 | 242024023@aluno.unb.br | Software
Yzabella Miranda Pimenta | 23/1039187 | Eng. de Software | (96) 99149-2546 | 231039187@aluno.unb.br | Gerente de área - Software

19

# 4 Projeto Conceitual do Produto

## 4.1 Características gerais

O Micromouse é um robô móvel autônomo desenvolvido para mapear e resolver labirintos desconhecidos em matrizes de 4 × 4, 8 × 8 e 16 × 16 células, com o objetivo de alcançar a região central no menor tempo possível. O produto integra tecnologias multidisciplinares, unindo uma estrutura física compacta a um ecossistema de software para monitoramento em tempo real.

O hardware é baseado no microcontrolador ESP32, utilizando sensores laser Timeof-Flight (ToF) para detecção de obstáculos e motores N20 com encoders para odometria. O sistema de software provê a observabilidade através de um dashboard web que exibe dados de telemetria, como trajeto, velocidade e consumo de bateria via Wi-Fi.

Os itens teóricos fundamentais para o sucesso do projeto, que serão detalhados oportunamente, compreendem:

- Dinâmica e Estabilidade: Cálculos de torque, potência e análise das condições de não-tombamento para garantir manobras seguras.
- Gestão Energética: Dimensionamento de baterias Li-Ion e eficiência de conversores DC-DC Buck para autonomia operacional.
- Algoritmos de Navegação: Aplicação de lógica Flood Fill para resolução de caminho e estratégias de exploração como DFS ou Tremaux.
- Arquitetura de Sistemas: Uso do FreeRTOS para processamento dual-core paralelo entre controle e telemetria.

4.1.1 Estrutura Analítica do Projeto

A Estrutura Analítica do Projeto (EAP) apresentada nesta seção é uma decomposição hierárquica orientada a entregas, porém, com foco no produto, organizada para facilitar o gerenciamento e o controle do escopo. O produto, e consequentemente o projeto, está dividido em cinco macroáreas principais:

- Estruturas (Laranja): Abrange o desenvolvimento da estrutura física do robô e do labirinto de teste, incluindo base, chassi, fixações, rodas e organização mecânica.
- Energia (Rosa): Envolve a definição e integração do sistema de alimentação, incluindo bateria, reguladores de tensão, distribuição de energia e proteção do circuito.

Capítulo 4. Projeto Conceitual do Produto | 20
- Sistema de software (Verde): Abrange o desenvolvimento da lógica de controle do robô, incluindo leitura dos sensores, controle dos motores, algoritmo de navegação e comunicação com o sistema embarcado.
- Sistema eletrônico embarcado (Azul): Envolve a integração dos componentes eletrônicos, como microcontrolador, sensores, driver dos motores, encoders e conexões elétricas do robô.
- Sistema integrado (Roxo): Abrange a integração entre estrutura, energia, eletrônica e software, incluindo montagem final, testes de funcionamento, ajustes e validação do robô no labirinto.

Capítulo 4. Projeto Conceitual do Produto 21 Figura 1 – Visualização geral da Estrutura Analítica do Projeto.

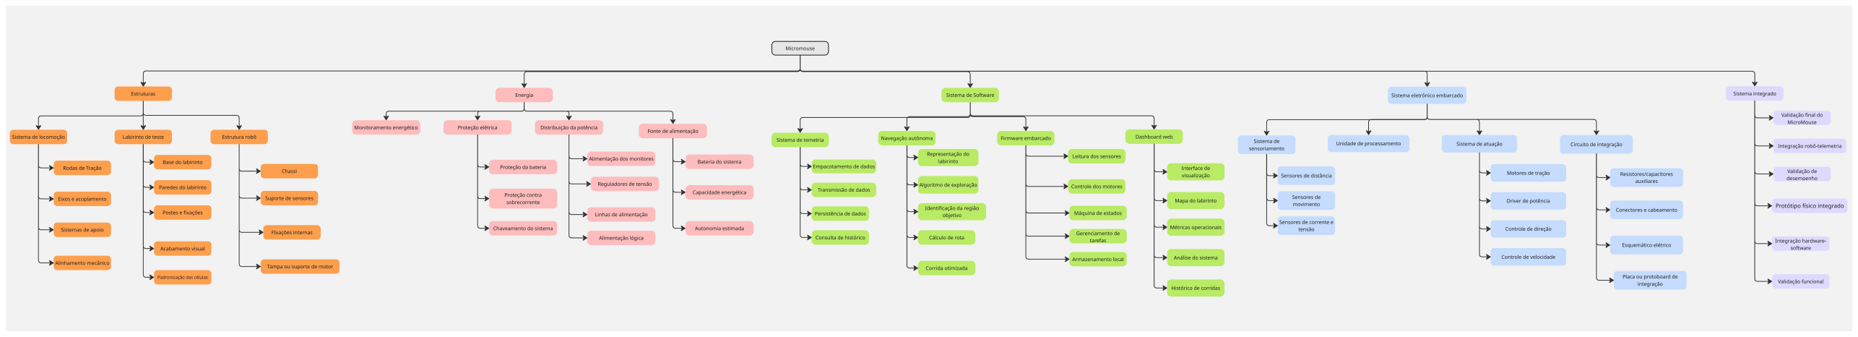
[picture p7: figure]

Capítulo 4. Projeto Conceitual do Produto 22 (a) Primeira parte expandida do EAP. (b) Segunda parte expandida do EAP. Figura 2 – Visualizações expandidas da Estrutura Analítica do Projeto.

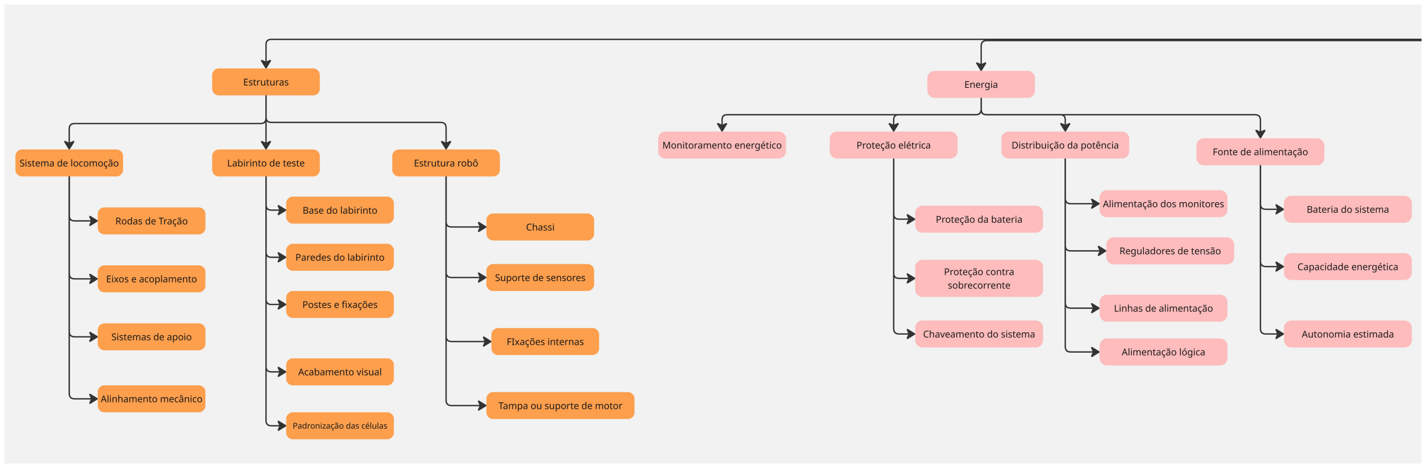
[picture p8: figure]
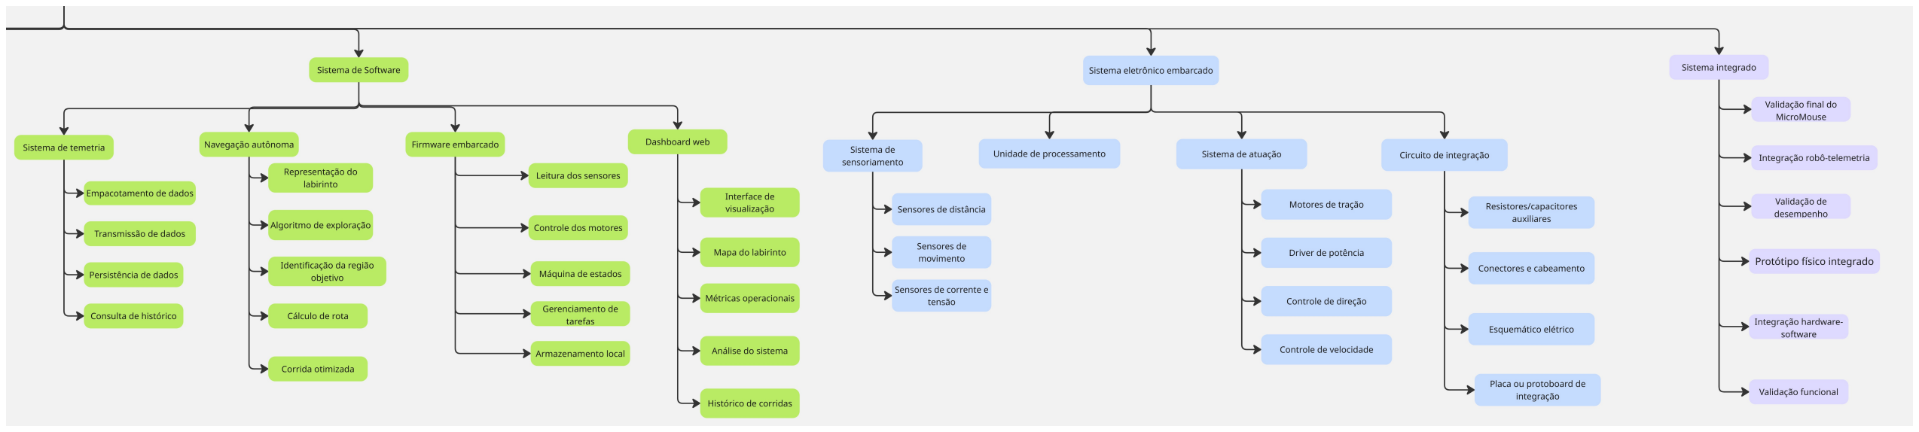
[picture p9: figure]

Capítulo 4. Projeto Conceitual do Produto | 23

## 4.2 Estrutura

Esta seção descreve a síntese do projeto mecânico do Micromouse, desenvolvido sob uma perspectiva técnica e funcional. A estrutura foi projetada para equilibrar a rigidez necessária à precisão dos sensores com a leveza exigida para acelerações rápidas, respeitando rigorosamente as normas internacionais de competições de Micromouse.

Para a validação das escolhas de engenharia, este documento detalha os cálculos para determinação de dimensões e seleção dos motores, desenhos técnicos que materializam a geometria adotada e a especificação técnica dos materiais aplicados tanto no chassi quanto no labirinto de testes.

4.2.1 Objetivo Geral

Projetar e validar a estrutura física de um robô autônomo (Micromouse) e seu ambiente de simulação, garantindo uma plataforma estável, leve e de baixo custo, capaz de realizar navegação precisa e manobras de alta performance em conformidade com os padrões competitivos.

4.2.1.1 Objetivos Específicos

- Dimensionamento Geométrico: Estabelecer as dimensões críticas do chassi (largura máxima de 110 mm) para garantir a manobrabilidade em trechos retilíneos e diagonais, evitando colisões com as paredes do labirinto.
- Otimização Dinâmica: Realizar o cálculo de torque e potência para a seleção do sistema motriz (GA12-N20), assegurando que o robô vença a inércia e mantenha a estabilidade (não-tombamento) em acelerações e frenagens bruscas.
- Desenvolvimento Estrutural: Projetar um chassi estratificado (dois níveis) que organize de forma estratégica a bateria, motores e sensores, otimizando o centro de massa e facilitando a manutenção dos componentes.
- Seleção de Materiais: Justificar o uso de materiais como PLA (impressão 3D) para o robô e MDF/EVA para o labirinto, focando na redução de peso e na qualidade da leitura dos sensores.
- Padronização do Ambiente: Construir um labirinto de testes modular que replique as condições reais de competição, permitindo a calibração fina dos algoritmos de busca e mapeamento.

Capítulo 4. Projeto Conceitual do Produto | 24

4.2.2 Dimensionamento Geométrico do Labirinto

4.2.2.1 Contexto e Normas do Labirinto

O labirinto oficial da competição Micromouse é composto por células quadradas de 18cm × 18cm, medidos de centro a centro das paredes. As paredes laterais possuem 5cm de altura e 1, 2cm de espessura. Esse padrão é adotado internacionalmente e define todas as restrições geométricas para o projeto do robô.

Considerando a espessura das paredes, o vão livre disponível para a movimentação do robô dentro de um corredor retilíneo é de:

18cm − 1, 2cm = 16, 8cm | (4.1)

Este valor é crítico porque representa o espaço real que o robô tem para efetuar o deslocamento sem tocar nas paredes laterais durante uma trajetória em linha reta. Além disso, para manobras que exigem uma rotação de 90∘ ou travessia diagonal de uma célula,

a geometria do labirinto impõe uma restrição mais severa: o robô não pode exceder a largura equivalente à diagonal do vão livre. O limite teórico para essa situação é:

Larguradiagonal = 16, 8cm ÷

√
2 ≈ 11, 88cm | (4.2)

O projeto do chassi deve respeitar ambos os limites:

- ≤ 16, 8cm para trechos retos;
- ≤ 11, 88cm para garantir operação em diagonal.

4.2.2.2 Materiais e Construção do Labirinto Teste

Para a construção do labirinto de testes, o projeto priorizou a modularidade e a fidelidade técnica às normas de competição. A estrutura baseia-se em uma malha de 4×4 células, totalizando 72cm de lado, com vãos livres de 168mm.

Optou-se por uma base em MDF de 6 mm, visando planicidade e uniformidade. Para as paredes, utilizou-se EVA de alta densidade de 12 mm, que oferece leveza e segurança contra impactos. A montagem utiliza 25 postes removíveis ancorados à base por suportes metálicos em “L”. As faces das paredes são revestidas com vinil branco fosco para otimizar os sensores ToF. O detalhamento geométrico completo (Figura 8) ilustra o posicionamento dos postes e as dimesões da labirinto de testes.

4.2.3 Dimensionamento Geométrico do Chassi

4.2.3.1 Arranjo Preliminar dos Componentes

- Bateria: Posicionada na parte traseira para estabilizar o centro de massa.

Capítulo 4. Projeto Conceitual do Produto | 25
- Motores: Localizados no centro do chassi para fornecer torque equilibrado às rodas.
- Sensores: Posicionados estrategicamente na dianteira para mapeamento e detecção de obstáculos.

4.2.3.2 Desenho Esquemático

O desenho técnico do chassi segue as larguras máximas de 160mm (retilíneo) e 118, 8mm (diagonal). A vista explodida do Robô evidencia a hierarquia de montagem e as premissas de estabilidade dinâmica e fácil acesso à manutenção através da tampa superior.

4.2.3.3 Vistas Técnicas

O desenho técnico do chassi (Figura 9) apresenta as principais dimensões e a localização de fixação dos componentes (motores, bateria e microcontrolador). As cotas estão expressas em milímetros e seguem as larguras máximas definidas anteriormente:

- 160 mm para deslocamento retilíneo;
- 118,8 mm para manobras diagonais.

4.2.3.4 Vista Explodida e Arranjo de Componentes

A vista explodida do robô (Figura 10) evidencia a disposição espacial dos 13 subsistemas principais, permitindo visualizar a hierarquia de montagem e a integração entre as partes mecânicas e eletrônicas.

Tabela 2 – Lista de Peças

Número Nome | Quantidade
1 | Chassis | 1
2 | Motor | 2
3 | Bateria | 1
4 | Microcontrolador | 1
5 | Lateral | 2
6 | Roda | 4
7 | Engrenagem | 2
8 | Protoboard 400 pinos | 1
9 | Protoboard 170 pinos | 2
10 | Tampa | 1
11 | Sensor Laser VL53l0x | 3
12 | Conversor DC-DC | 2
13 | Driver para motor | 1

O arranjo foi projetado seguindo as seguintes premissas:

Capítulo 4. Projeto Conceitual do Produto | 26
- Estabilidade Dinâmica: A bateria (item 3) e os motores (item 2) estão fixados no chassi inferior (item 1), mantendo o centro de massa o mais próximo possível do solo e garantindo estabilidade em curvas.
- Acesso à manutenção: A tampa (item 10) permite a separação funcional dos componentes. Aqueles que não necessitam de acesso constante (motores, bateria) são alocados no chassi (item 1). Os elementos que exigem intervenção constante para depuração e calibração ficam acessíveis no plano superior. Além de prover proteção passiva, a tampa integra aberturas para o gerenciamento de cabos.
- Interface de sensoriamento: Os suportes dos sensores laser (item 11) foram posicionados nas extremidades da base, assegurando que o envelope de leitura não sofra interferência das rodas ou da tampa superior.

4.2.3.5 Visão Isométrica

A perspectiva isométrica do Micromouse (Figura 11) consolida o design tridimensional, permitindo a visualização do robô em seu estado final de montagem.

- Validação volumétrica: Demonstra a capacidade do conjunto e seu respeito às dimensões do labirinto.

4.2.4 Dimensionamento dos Motores

Pela Segunda Lei de Newton, a força trativa (Ft) deve superar a resistência ao rolamento (Frr) para imprimir uma aceleração constante (a):

Crr =

b
R
; | Frr = Crr · m · g | (4.3)

Onde b é o coeficiente de atrito de rolamento, R o raio da roda, m a massa (m ≤ 0, 250kg) e g a aceleração da gravidade. A força trativa total é dada por:

Ft = m · (a + Crr · g) | (4.4)

O torque mínimo (Tmin) e o torque de projeto com margem (Tproj ) são definidos, respectivamente, pelas equações 4.5 e 4.6:

Tmin = Ft

- R | (4.5)
Tproj = Tmin · 1, 3 | (4.6)

Capítulo 4. Projeto Conceitual do Produto | 27

4.2.4.1 Desenvolvimento Matemático

Adotou-se b = 1, 5mm (silicone sobre madeira pintada) e R = 22, 5mm. Os cálculos seguem no Sistema Internacional (SI):

Frr =

(︃
1, 5
22, 5

)︃
- 0, 25 · 9, 81 = 0, 1635N | (4.7)

Logo, a força trativa para uma aceleração de 1m/s² é:

Ft = 0, 25 · 1 + 0, 1635 = 0, 4135N | (4.8)

O torque mínimo total e o torque por motor (dividido por 2 com margem de 30%) resultam em:

Tmin ≈ 9, 31N.mm =⇒ Tmin_motor_proj =

9, 31 · 1, 3
2

= 6, 0515N.mm (4.9)

4.2.4.2 Conclusão e Validação

Comparando os valores calculados com o datasheet do motor GA12-N20-S0310D-E:

Tabela 3 – Validação do torque do motor GA12-N20

Parâmetro | Valor Datasheet | Valor (N.mm) | Status
Torque Nominal | 2,9 kg.mm | 28,44 N.mm | Validado (> 6, 05)
Torque de Estol | 17 kg.mm | 166,71 N.mm | Validado (> 6, 05)

4.2.5 Condições de Não-Tombamento

4.2.5.1 Objetivo e Fundamentação Teórica

O objetivo desta análise é determinar a altura máxima permitida para o Centro de Gravidade (CG), de forma a garantir que o veículo permaneça estável e não capote durante frenagens bruscas.

Na iminência de tombamento, a força Normal no eixo traseiro torna-se nula. A estabilidade é mantida enquanto o torque restaurador for superior ao torque de tombamento:

- Torque Restaurador: Gerado pela componente vertical do peso.
- Torque de Tombamento: Gerado pela força de inércia resultante da desaceleração.

Capítulo 4. Projeto Conceitual do Produto | 28

4.2.5.2 Desenvolvimento Matemático

A condição de estabilidade em relação ao eixo frontal é definida por:

τrestaurador ≥ τtombamento =⇒ P · x ≥ F · ℎmáx | (4.10)

Considerando que a força de desaceleração máxima é limitada pelo atrito estático (μe), temos F = P · μe. Assim:

P · x ≥ (P · μe) · ℎmáx =⇒ ℎmáx ≤

x
μe

(4.11)

Para uma distribuição de massa ideal, onde o CG está no centro geométrico (x = L/2):

ℎmáx ≤

L
2 · μe

(4.12)

Dados os parâmetros do projeto:

- μe = 0, 7
- L = 0, 1225 m

ℎmáx ≤

0, 1225
2 · 0, 7
≈ 0, 0875m =⇒ ℎmáx ≤ 8, 75cm | (4.13)

4.2.5.3 Conclusão

A análise do projeto mecânico confirma que o robô está tecnicamente apto para a competição. Com largura de 110mm e centro de gravidade otimizado, o Micromouse garante agilidade sem risco de colisões ou tombamentos. O sistema motriz validado e o labirinto de testes fiel às normas consolidam uma base sólida para a integração final dos algoritmos de navegação autônoma.
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

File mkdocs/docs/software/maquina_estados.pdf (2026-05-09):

## Arquitetura do Firmware: Máquina de Estados

A Figura ?? ilustra o Diagrama de Máquina de Estados UML que descreve o comportamento lógico do rmware do robô Micromouse. O diagrama mapeia todos os estados operacionais e de falha, bem como as condições e comandos que disparam as transições entre eles.

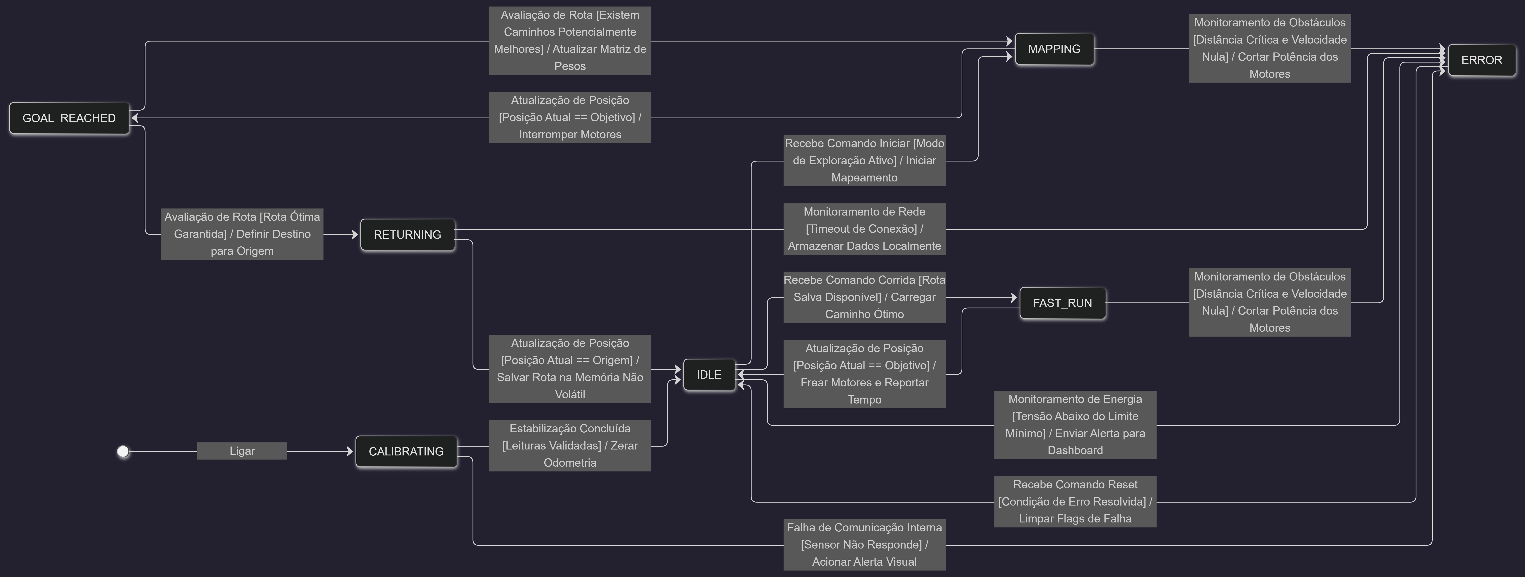
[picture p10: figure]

Figura 1: Diagrama de Máquina de Estados do Firmware do Micromouse.

A Tabela ?? detalha as transições de estado, descrevendo os eventos ou gatilhos técnicos (sensores, timers, comandos) e os respectivos estados de destino. Estes estados servem como a principal tag de indexação no banco de dados InuxDB para telemetria.

1

Evento / Condição | Descrição do Gatilho | Estado de Destino
Ligar o Robô | Ligar a alimentação e iniciar o sistema. | CALIBRATING
Fim da Calibração | Sensores ToF e IMU estabilizados, Encoders zerados. | IDLE
Comando de Exploração | Recebimento de sinal de início via sistema (dashboard) ou botão físico. | MAPPING
Objetivo Encontrado | Odometria e sensores indicam a chegada ao centro do labirinto. | GOAL_REACHED
Caminho Incompleto | O algoritmo de navegação (ex: Flood Fill) identica que ainda existem rotas inexploradas que podem ser mais curtas. | MAPPING

Caminho
Finalizado

O algoritmo de avaliação garante que a rota calculada é matematicamente a mais curta (Rota Ótima).

RETURNING

Chegada na Base Odometria indica o retorno seguro ao ponto de origem (célula de largada). IDLE

Comando Rápido Sinal para execução de corrida em velocidade máxima usando a rota salva. FAST_RUN

Fim da Corrida | Chegada ao centro da pista após a execução da rota otimizada.
IDLE
Falhas Críticas (HW/SW) | Leitura do sensor INA219 indica bateria abaixo do li- miar crítico, perda de Wi-Fi, ou sensores indicam co- lisão/travamento (ocorre a partir de qualquer estado).
ERROR

Recuperação
(Reset)

Sinal de reset enviado pelo usuário via dashboard ou botão após a inspeção da pista e resolução da falha.

IDLE

Tabela 1: Tabela Descritiva das Transições da Máquina de Estados.

2

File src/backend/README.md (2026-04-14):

# _Backend_

Esta pasta deverá armazenar arquivos referentes a:

- Código-fonte da API REST: rotas, controladores, modelos e lógica de negócio.
- Arquivos de configuração do servidor: `app.py`, `server.js`, `main.go` etc., dependendo da linguagem/framework utilizado ([Flask](https://flask.palletsprojects.com/), [FastAPI](https://fastapi.tiangolo.com/), [Express](https://expressjs.com/), [Django](https://www.djangoproject.com/) etc.).
- Arquivos de definição de dependências: `requirements.txt` ou `pyproject.toml` (Python), `package.json` (Node.js), `pom.xml` (Java/Maven) etc.
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

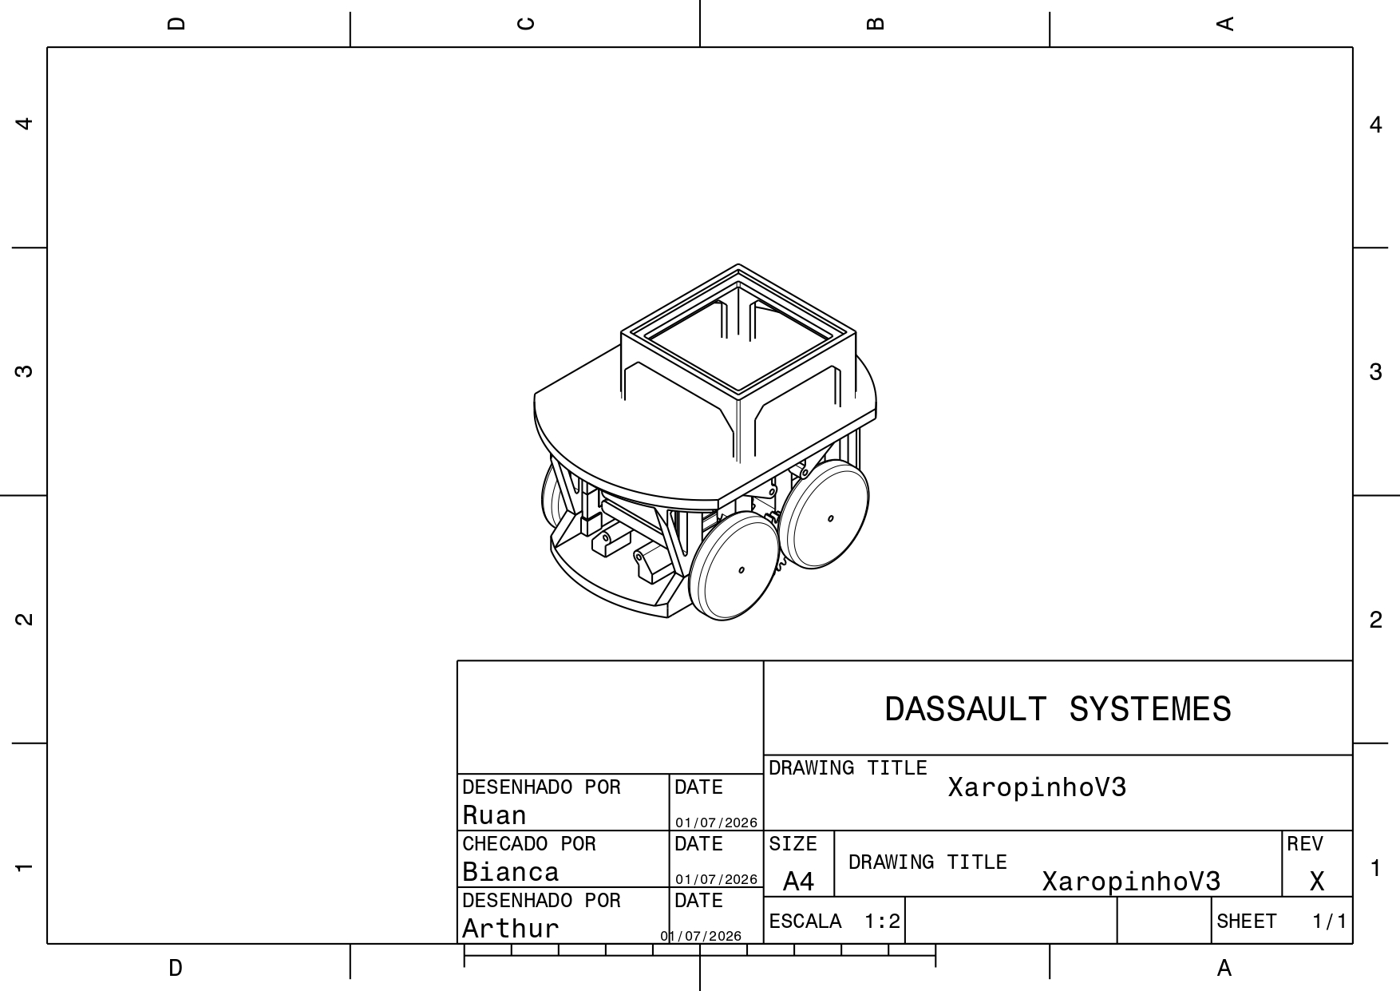
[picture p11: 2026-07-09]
docs/relatorio/editaveis/XaropinhoV3 isomérica.jpg

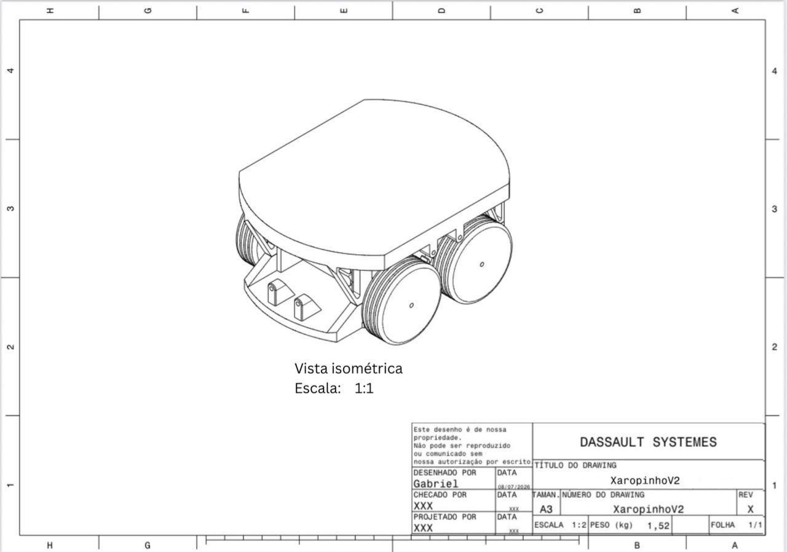
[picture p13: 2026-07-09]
docs/relatorio/editaveis/XaropinhoV2 Isomérica.jpg

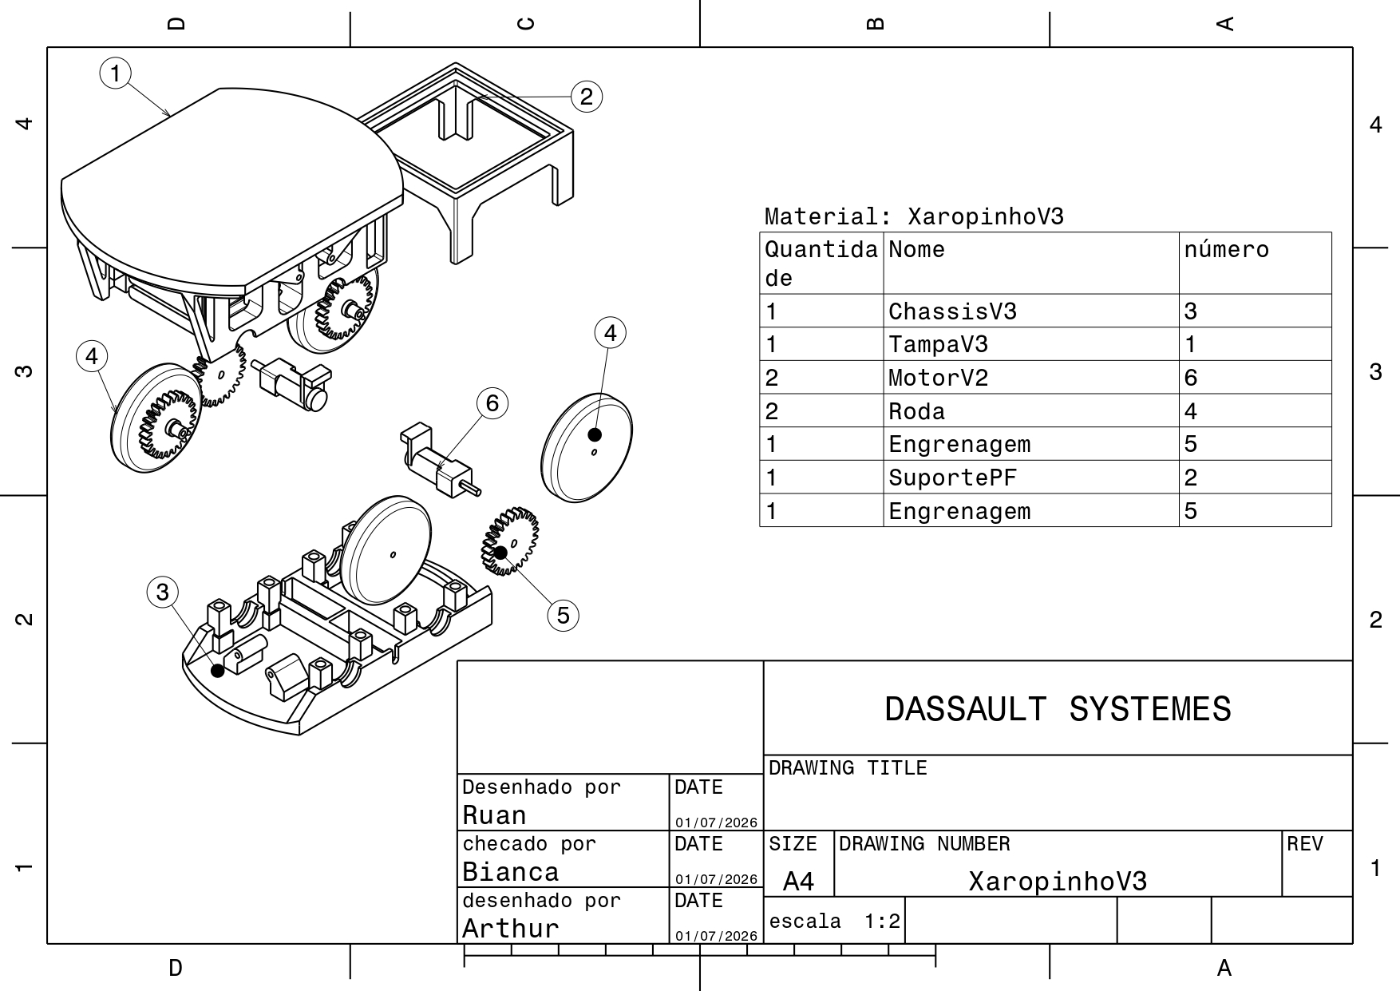
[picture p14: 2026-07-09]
docs/relatorio/editaveis/XaropinhoV3 Explodida.jpg

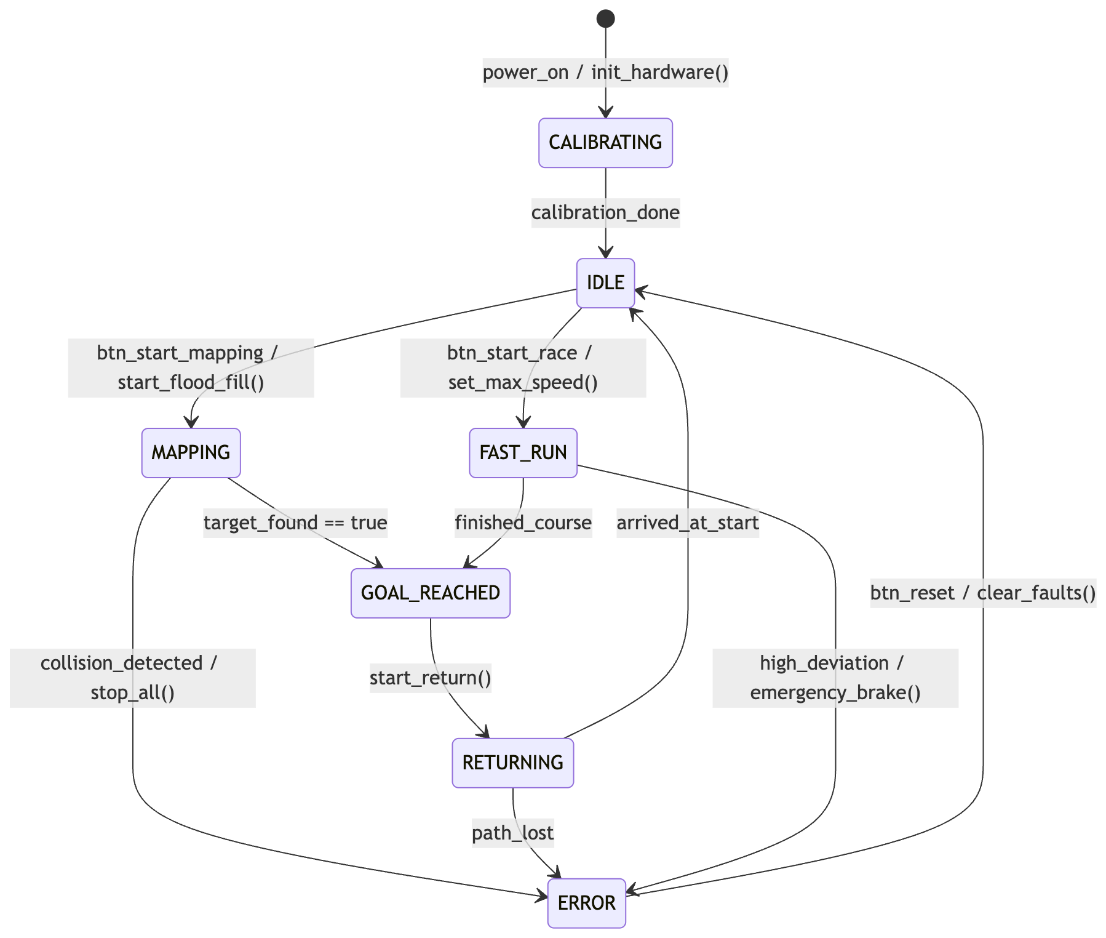
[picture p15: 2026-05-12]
docs/relatorio/figuras/diagrama_estados.png

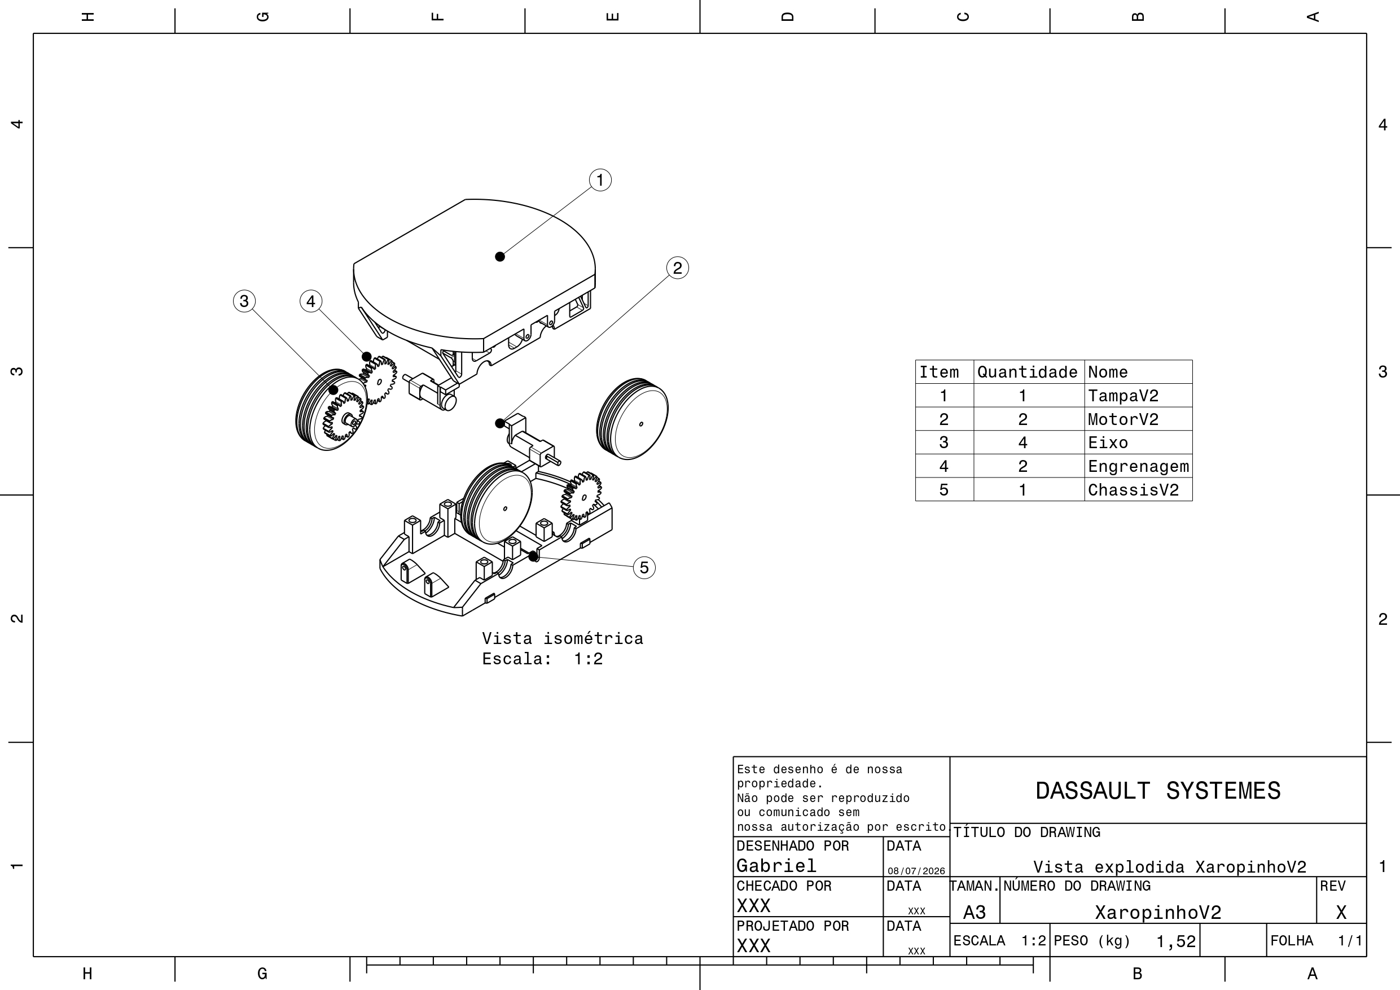
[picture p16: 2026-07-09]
docs/relatorio/editaveis/XaropinhoV2 Explodida.jpg

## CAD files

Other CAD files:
mec/XaropinhoV1/Bateria.CATPart
mec/XaropinhoV1/Chassis.CATPart
mec/XaropinhoV1/Conversor DC-DC .CATPart
mec/XaropinhoV1/Driver p motor.CATPart
mec/XaropinhoV1/Engrenagen.CATPart
mec/XaropinhoV1/Lateral.CATPart
mec/XaropinhoV1/MicroControlador.CATPart
mec/XaropinhoV1/Motores.CATPart
mec/XaropinhoV1/Protoboard 170 pinos.CATPart
mec/XaropinhoV1/Protoboard.CATPart
mec/XaropinhoV1/Roda.CATPart
mec/XaropinhoV1/Sensor .CATPart
mec/XaropinhoV1/Symmetry of Engrenagen.CATPart
mec/XaropinhoV1/Symmetry of Lateral.CATPart
mec/XaropinhoV1/Symmetry of Motores.CATPart
mec/XaropinhoV1/Symmetry of Roda.CATPart
mec/XaropinhoV1/Symmetry of Sensor Laser Vl53l0x.CATPart
mec/XaropinhoV1/Tampa.CATPart
mec/XaropinhoV1/XaropinhoV1.CATProduct

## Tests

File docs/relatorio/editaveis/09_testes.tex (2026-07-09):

\chapter{Testes de Verificação e Validação}
\label{testes}

\section{Características Gerais}

Este capítulo apresenta os testes de verificação e validação realizados no projeto Micromouse, com o objetivo de avaliar se os subsistemas desenvolvidos atendem aos requisitos definidos e se, quando integrados, são capazes de operar de forma coerente com a proposta do produto. Os ensaios contemplam aspectos estruturais, eletrônicos, energéticos, de software e de integração global, considerando tanto a análise individual dos componentes quanto o comportamento do sistema completo.

\section{Testes da Estrutura}

Esta seção apresenta os ensaios e metodologias de verificação e validação aplicados ao ecossistema estrutural do Micromouse. O propósito fundamental desta etapa consiste em assegurar que o chassi manufaturado e o ambiente de testes físico repliquem com fidelidade as premissas analíticas estabelecidas no projeto conceitual. Para tanto, avaliam-se parâmetros críticos de tolerância dimensional, estabilidade cinemática, rigidez a impactos e a dinâmica de rolamento do sistema de locomoção.

\subsection{Inventário Físico e Conformidade de Peças}

O primeiro estágio de verificação consistiu na conferência e inspeção individual dos componentes estruturais manufaturados antes da integração final do sistema. A Figura~\ref{fig:pecas_separadas} apresenta o inventário físico dos elementos mecânicos brutos obtidos por impressão 3D em PLA, dispostos em bancada para fins de verificação de qualidade.

A análise visual das peças físicas revela um alto nível de fidelidade geométrica na deposição das camadas de filamento, mantendo a integridade estrutural das furações concêntricas de fixação dos motores e dos encaixes dos rolamentos das rodas. Na imagem, observa-se o conjunto básico de sustentação e transmissão do robô, composto pelas duas seções principais do chassi (base inferior de fixação e estrutura superior de proteção), 4 unidades de rodas com sulcos para acoplamento de pneus e 2 engrenagens cilíndricas de dentes retos destinadas à redução e transmissão do sistema motriz.

\begin{figure}[htbp]
    \centering
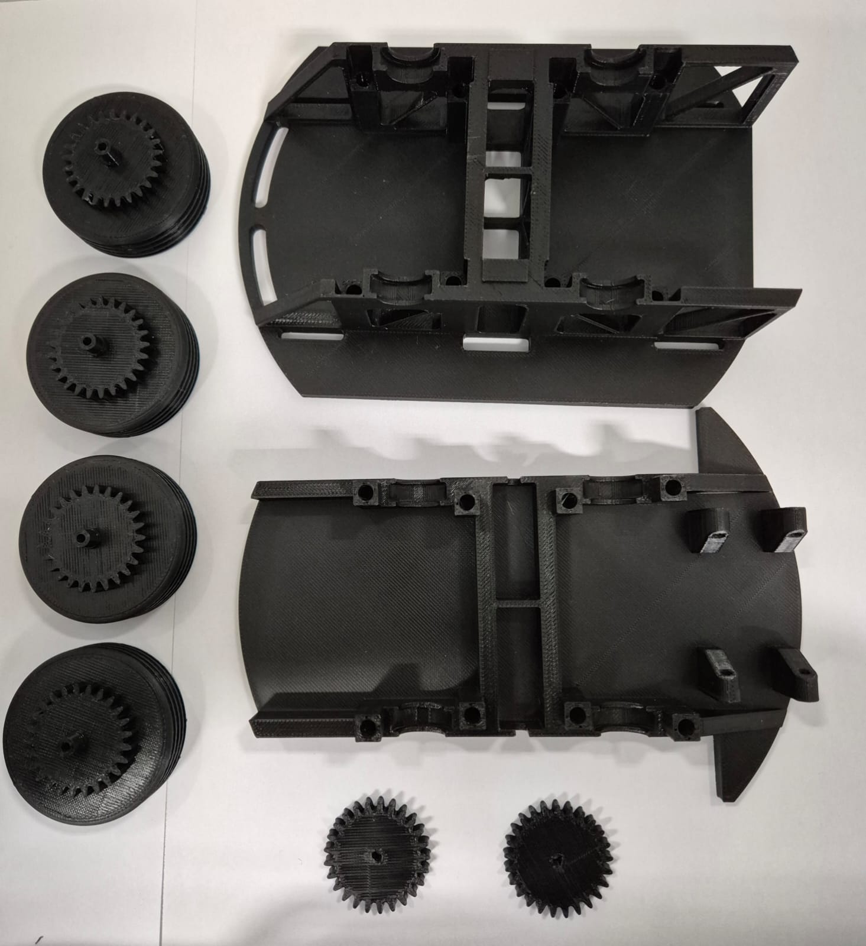
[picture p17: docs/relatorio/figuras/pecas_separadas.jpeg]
    
    \caption{Componentes estruturais e mecânicos do micromouse manufaturados em PLA.}
    \label{fig:pecas_separadas}
\end{figure}

Para fins de rastreabilidade e controle de qualidade industrial, a disposição e a correta identificação geométrica de cada um desses 8 subsistemas podem ser correlacionadas diretamente com o diagrama técnico de detalhamento e a listagem estruturada presentes na Figura~\ref{fig:Draft Micromouse explodido}.

\subsubsection{Montagem Estrutural e Consistência com o Modelo CAD}

Após o inventário inicial, executou-se a montagem mecânica do chassi para análise de rigidez e acoplamento. A Figura~\ref{fig:estrutura_montada} ilustra a carcaça do Micromouse montada, evidenciando o posicionamento preliminar de componentes de fiação e elementos eletrônicos internos em seus respectivos nichos de fixação. Para assegurar a estabilidade mecânica do conjunto e mitigar vibrações estruturais que possam comprometer as leituras dos sensores, a união entre os planos estratificados foi realizada de forma híbrida, empregando guias de encaixe por pressão integradas ao design do PLA em conjunto com elementos de fixação roscados (parafusos metálicos passantes).

\begin{figure}[htbp]
    \centering
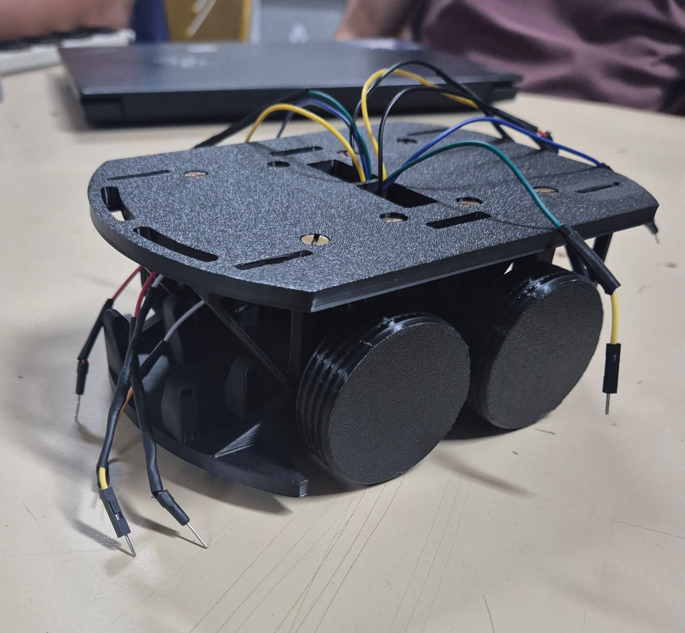
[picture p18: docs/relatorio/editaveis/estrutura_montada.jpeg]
    
    \caption{Estrutura do chassi montada com parafusos e encaixes, com fiação e hardware interno preliminar.}
    \label{fig:estrutura_montada}
\end{figure}

Essa configuração física comprova a eficiência do projeto estrutural em prover proteção passiva aos componentes internos, mantendo o acesso para manutenção prático. Para certificar que a execução real não divergiu das premissas geométricas teóricas, o protótipo montado foi confrontado com o ambiente virtual. A Figura~\ref{fig:carro_cad} expõe o modelo tridimensional renderizado em ambiente CAD, servindo como ferramenta de controle de qualidade para atestar que as furações concêntricas de união, os suportes de sensoriamento e as folgas de acoplamento foram rigorosamente respeitados. A validação dessa montagem estratificada toma como referência técnica a vista explodida oficial do projeto, documentada detalhadamente no desenho técnico presente na Figura~\ref{fig:Draft Micromouse explodido}.

\begin{figure}[htbp]
    \centering
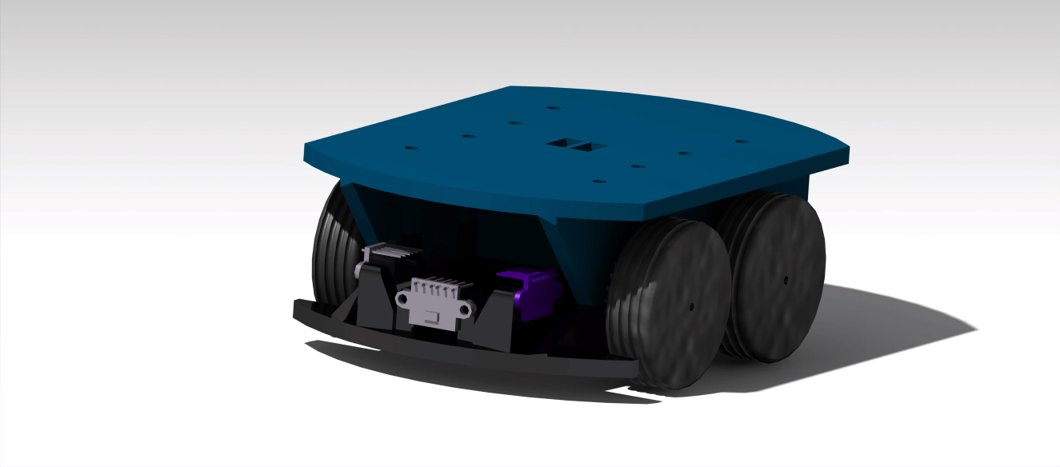
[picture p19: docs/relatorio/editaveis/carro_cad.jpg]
    
    \caption{Ilustração do veículo completamente montado em ambiente virtual CAD.}
    \label{fig:carro_cad}
\end{figure}

\subsection{Ensaios de Verificação Dimensional e de Tolerâncias}
Utilizando instrumentos de medição de precisão (paquímetro), aferiu-se o envelope volumétrico final do robô montado. Os resultados confirmaram que o chassi manteve a largura nominal de $110 mm$ e o comprimento de $156 mm$ dentro de uma margem de tolerância física de $\pm 0,5mm$, validando a conformidade com o projeto conceitual e o CAD elaborado.

Estas dimensões críticas e os limites de tolerância adotados na fabricação foram validados e estão devidamente cotados nas projeções ortogonais (vistas superior, lateral e seções transversais) localizadas na Figura~\ref{fig:carro_cad}.

\subsection{Validação de Locomoção, Rodas e Rolamentos}
O sistema de suspensão estática e acoplamento dos eixos passou por ensaios cinemáticos para verificar o alinhamento das rodas e a eficiência dos rolamentos. O conjunto apresentou baixo coeficiente de fricção interna, assegurando que o torque fornecido pelos motores GA12-N20-S0310D-E seja eficientemente convertido em força trativa.

\subsection{Testes Dinâmicos de Curvas no Labirinto}

O robô foi submetido a ensaios práticos de rotação de $90^{\circ}$ e deslocamentos em trajetórias diagonais dentro do labirinto modular. Inicialmente, o teste comprovou empiricamente o cálculo teórico de folga espacial lateral, estabelecido em $\le 16,80 cm$. O arranjo recuado do sistema de rodagem e o chanfro projetado nas extremidades do chassi mostraram-se eficazes em evitar colisões ou raspagens contra as paredes do ambiente de testes durante manobras controladas em baixa velocidade.

Contudo, observou-se que o comprimento diagonal total do Micromouse é de $160 mm$, o que estabelece uma margem geométrica extremamente estreita e intolerante a pequenas derivas ou erros de alinhamento cinemático. Diante do risco iminente de colisões durante transições rápidas, os ensaios dinâmicos atuaram como um balizador para decisões de projeto. 

Como ação corretiva e de otimização para o próximo ponto de controle, determinou-se a reestruturação e o rearranjo dos componentes eletrônicos dispostos interna e externamente na estrutura estratificada. Essa reorganização do leiaute visa otimizar o espaço interno dedicado ao acondicionamento dos módulos, viabilizando a diminuição do raio dimensional do chassi e, por consequência, contraindo a sua diagonal geométrica. Como resultado, o Micromouse obterá uma margem de segurança significativamente maior contra colisões, garantindo a estabilidade operacional e a integridade do robô durante curvas e manobras severas em alta velocidade. Ressalta-se que tais modificações estruturais serão conduzidas de modo a respeitar estritamente a identidade visual, a distribuição de massas e as diretrizes funcionais consolidadas no projeto conceitual.

\subsection{Ensaio de Resistência a Impactos}
Por fim, realizou-se um teste de resistência passiva estrutural submetendo o chassi a pequenas colisões frontais e laterais simuladas em velocidade nominal. A estrutura absorveu satisfatoriamente a energia cinética dos impactos devido à flexibilidade controlada e preenchimento interno do filamento PLA, garantindo proteção total aos sensores ToF e circuitos internos sem apresentar trincas, fraturas ou folgas nos encaixes da tampa superior.

\section{Testes de \textit{hardware}}

Essa seção tem como principal objetivo explicitar os testes de \textit{hardware} realizados para a construção e funcionamento do MicroMouse. Dessa forma, apresentaremos os testes de processamento, sensores, armazenamento e comunicações.

\subsection{Processamento - ESP32}

A interface de desenvolvimento escolhida pela equipe foi a \textbf{ESP-IDF}. A escolha se deu, principalmente, por afinidade de alguns membros do grupo de eletrônica. Além disso, a interface possui amplo suporte a todas as funcionalidades da ESP32 que serão utilizadas, e boa integração com o Visual Studio Code, o editor de código utilizado pela equipe. 

Assim, foi rodado um exemplo mínimo no qual testamos a ESP32 para fazer a rotação simples de um dos motores, na primeira montagem realizada pela equipe. O teste resultou em sucesso e conseguiu-se acionar o motor via ESP32. Esse teste pode ser encontrado na Figura \ref{fig:exemploMin}.

Após isso, também fizemos os testes com os dois atuadores, os motores, realizando testes de mudança de direção e velocidade, sendo todos bem sucedidos.

\begin{figure}[htbp]
    \centering
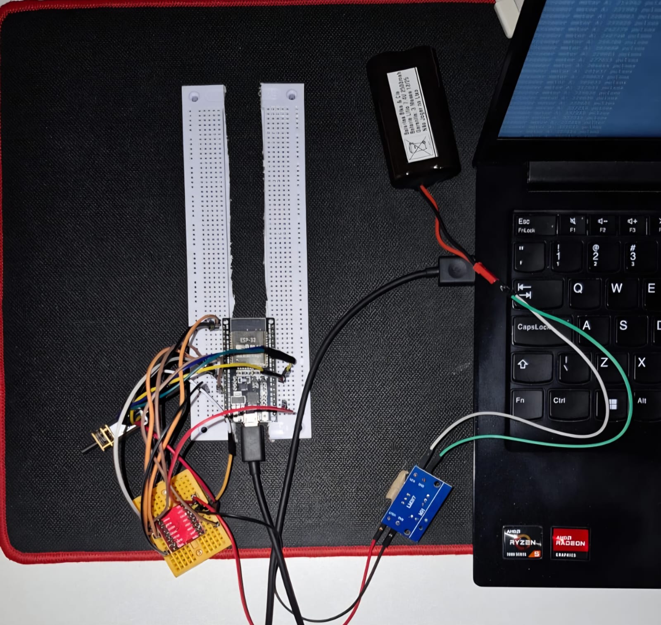
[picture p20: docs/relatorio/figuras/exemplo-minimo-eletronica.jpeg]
    
    \caption{Teste de processamento de exemplo mínimo}
    \label{fig:exemploMin}
\end{figure}

\subsection{Sensores}

Os sensores utilizados pela equipe são: 
\begin{itemize}
    \item 1 INA219;
    \item 2 Encoders relacionados aos motores;
    \item 3 ToF VL53L0X.
\end{itemize}

\subsubsection{Leitura básica de dados}
Iniciamos os testes dos sensores com a realização de leitura básica dos dados dos sensores ToF, INA219 e dos encoders. Dessa forma, nessa primeira etapa, não foi feita a validação e calibragem das leituras, sendo o foco apenas a leitura dos dados. 

As Figuras \ref{fig:leituraToF}, \ref{fig:leituraINA} e \ref{fig:leituraEncoders} mostram a leitura básica de todos os sensores utilizados. Cabe lembrar que para os sensores que se repetem, colocamos apenas uma foto da execução do teste no relatório, porém todos foram testados e aprovados.

\begin{figure}[htbp]
    \centering
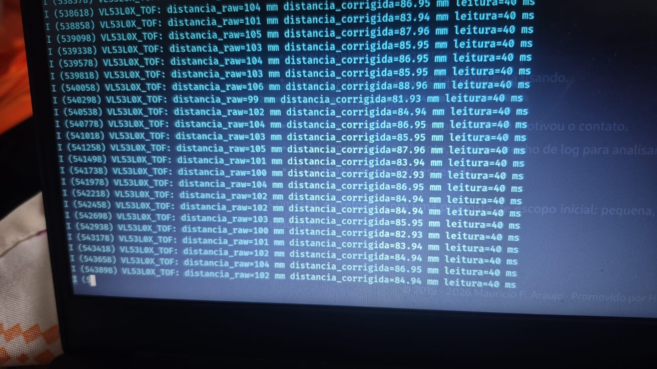
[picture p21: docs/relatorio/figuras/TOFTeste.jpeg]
    
    \caption{Leitura básica do ToF}
    \label{fig:leituraToF}
\end{figure}

\begin{figure}[htbp]
    \centering
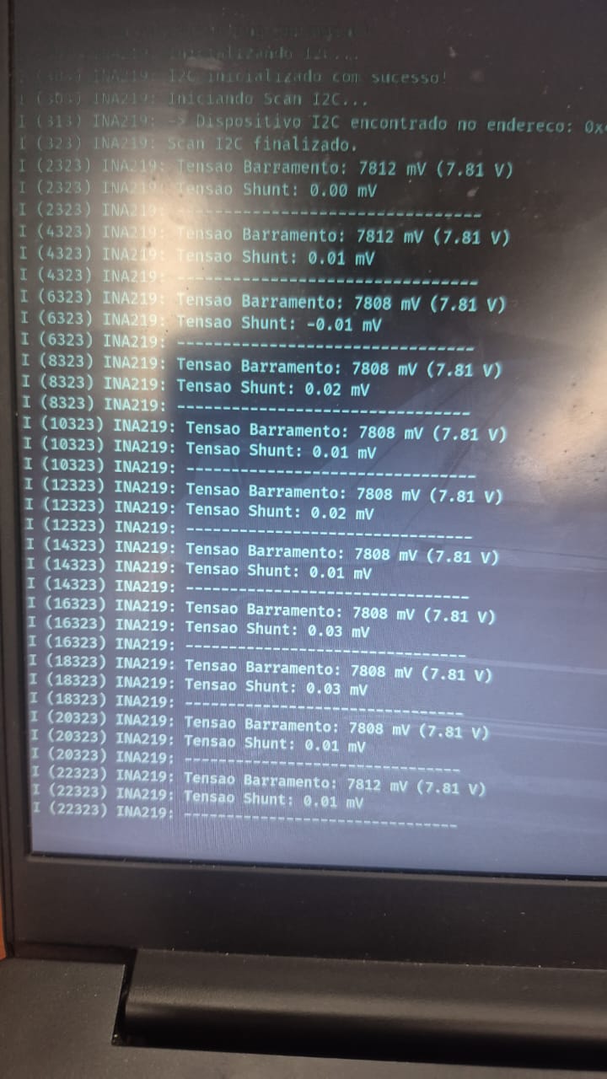
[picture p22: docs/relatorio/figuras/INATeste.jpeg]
    
    \caption{Leitura básica do INA219}
    \label{fig:leituraINA}
\end{figure}

\begin{figure}[htbp]
    \centering
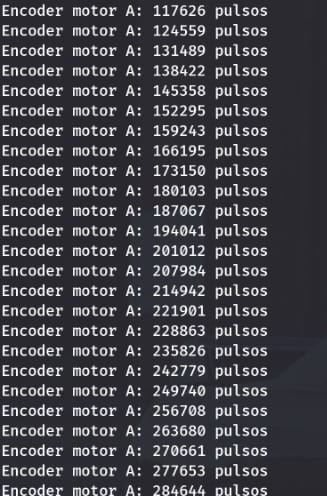
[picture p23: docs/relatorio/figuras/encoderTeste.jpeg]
    
    \caption{Leitura básica dos encoders}
    \label{fig:leituraEncoders}
\end{figure}

\subsubsection{Validação e calibragem de leituras}

A calibragem dos sensores ToF foi feita a partir de medições reais comparadas com as medições do sensor, montamos primeiro um gráfico sendo o eixo x as medições reais, e o eixo y sendo as medições feitas pelo sensor ToF. Depois fizemos pelo método de regressão linear dos mínimos quadrados uma reta no formato $a \times x + b$ para achar a reta mais próxima. 

Por fim, chegamos a reta $0.9951 \times x + 17.475$, a qual usamos da seguinte forma para corrigir as leituras do sensor: $real = 0.9951 \times sensor - 17.475$; e depois aplicamos o filtro EMA \cite{pieterp_ema} que consistem em:

\begin{equation}
y[n] = \alpha x[n] + (1-\alpha)y[n-1]
\end{equation}

onde:
\begin{itemize}
    \item $y[n]$ medição filtrada, na iteração $n$;
    \item $x[n]$ valor real medido;
    \item $y[n-1]$ valor filtrado anteriormente;
    \item $\alpha$ fator de filtragem $0 \leq \alpha \leq 1$.
\end{itemize}

Para permitir que o robô realize curvas com ângulos específicos, irá adotada uma estratégia de calibração baseada na contagem de pulsos do encoder.

Como o sistema ainda não possui informações precisas sobre as dimensões mecânicas do conjunto de tração, optou-se por uma abordagem experimental. Inicialmente, os contadores de pulsos são zerados e o robô realiza uma rotação completa de 360° em torno do próprio eixo. Ao final da manobra, registra-se a quantidade total de pulsos gerados pelo encoder.

Esse valor passa a ser utilizado como referência para determinar a quantidade de pulsos necessária para qualquer outro ângulo de rotação. A relação é obtida por meio de uma regra de três:

$$
P_{\theta}=\frac{\theta \cdot P_{360}}{360}
$$

onde:
\begin{itemize}
    \item \(P_{360}\) é a quantidade de pulsos medida durante a rotação completa;
    \item \(P_{\theta}\) é a quantidade de pulsos correspondente ao ângulo desejado;
    \item \(\theta\) representa o ângulo de rotação solicitado.
\end{itemize}

A Figura \ref{fig:calibragemTOF} registra a calibragem feita para os sensores ToF. 

\begin{figure}[htbp]
    \centering
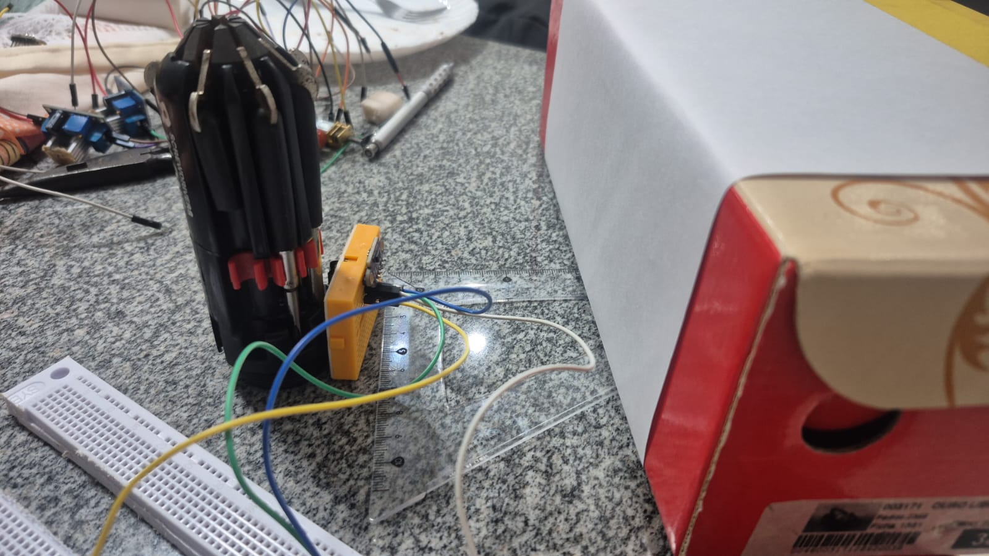
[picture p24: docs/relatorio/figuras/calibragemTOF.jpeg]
    
    \caption{Realização da calibragem dos ToFs}
    \label{fig:calibragemTOF}
\end{figure}
    
\subsection{Armazenamento}

O armazenamento dos dados coletados pelos sensores está sendo feito a partir da telemetria com sockets UDP para o servidor web local na mesma rede WIFI que a ESP32 está conectada. Estamos utilizando oInfluxDB, um banco de dados de séries temporais, usado em projetos que armazenam dados que mudam em relação ao tempo, para persistência dos dados registrados pelos sensores utilizados para o funcionamento do MicroMouse.

\subsection{Comunicações}

A comunicação é feita via sockets UDP para o servidor \textit{backend} local em um computador conectado a mesma rede WIFI que a ESP32. Ela acontece em paralelo, pinada a um \textit{core} da ESP32 enquanto o processamento dos dados e tomadas de decisões acontece em outro \textit{core}.

\begin{comment}
\textcolor{red}{Apresentar com detalhes os testes feitos para conferir se os objetivos do \textit{hardware} foram atendidos, incluindo:}

\begin{enumerate}
    \item \textcolor{red}{Processamento (Arduino, ESP32 etc):}
    \begin{itemize}
        \item \textcolor{red}{Definir interface de desenvolvimento;}
        \item \textcolor{red}{Rodar exemplo mínimo.}
    \end{itemize}
    \item \textcolor{red}{Sensores (temperatura, pressão, posição, velocidade etc.):}
    \begin{itemize}
        \item \textcolor{red}{Realizar leitura básica de dados;}
        \item \textcolor{red}{Validar/calibrar leituras;}
        \item \textcolor{red}{Definir taxas de amostragem e quantidade de dados para transmissão e/ou armazenamento;}
        \item \textcolor{red}{Validar taxas definidas e quantidade de dados;}
        \item \textcolor{red}{Realizar processamento básico de dados (\textit{thresholding}, filtro média-móvel etc.).}
    \end{itemize}
    \item \textcolor{red}{Armazenamento (memória interna, cartão SD, pendrive etc.):}
    \begin{itemize}
        \item \textcolor{red}{Armazenar dados básicos;}
        \item \textcolor{red}{Armazenar e validar dados de sensores.}
    \end{itemize}
    \item \textcolor{red}{Atuadores (Motores DC, relés, LEDs etc.):}
    \begin{itemize}
        \item \textcolor{red}{Realizar acionamentos básicos;}
        \item \textcolor{red}{Realizar acionamentos com base em dados de sensores;}
        \item \textcolor{red}{Realizar processamento básico de dados (PWM etc.).}
    \end{itemize}
    \item \textcolor{red}{Comunicações (UART, I2C, SPI, USB, WiFi, Bluetooth etc.):}
    \begin{itemize}
        \item \textcolor{red}{Transmissão básica de dados;}
        \item \textcolor{red}{Transmissão de dados de sensores dentro da taxa de amostragem.}
    \end{itemize}
\end{enumerate}
\end{comment}

\section{Testes de consumo energético}

Os testes da área de energia têm como objetivo garantir que a bateria escolhida irá satisfazer os parâmetros levantados na fase de dimensionamento energético.

\subsection{Característica da bateria}

Primeiro foi conferido na embalagem do produto se certas características correspondiam com o que era esperado da bateria, as informações verificadas estão na tabela \ref{tab:caracteristicas_bateria_validadas}.

\begin{table}[htpb]
\begin{center}
\caption{Características da bateria escolhida.}
\label{tab:caracteristicas_bateria_validadas}
\begin{tabular}{|p{4cm}|p{4cm}|p{4cm}|}
\hline
\textbf{Parâmetro} & \textbf{Valor} & \textbf{Validado} \\ \hline
Química  & Lítio-Polímero (Lipo) & Sim \\ \hline
Configuração & 2 células & Sim\\ \hline
Tensão Nominal & $7,4V$ & Sim\\ \hline
Capacidade & $2200 mAh$ & Sim\\ \hline
\end{tabular}
\end{center}
\end{table}

\subsection{Teste em Repouso}

Depois da validação das especificações, foi feito o teste em repouso, afim de validar que a tensão da bateria era maior ou igual a tensão esperada. Foi utilizado um multímetro e a tensão medidda foi igual a $8,63 volts$, sendo validada a tensão em repouso uma vez que a tensão em repouso obtida é maior do que a esperada, que era de $7,4\ volts$. É possível visualizar o resultado na figura \ref{fig:Teste tensao bateria}.

    \begin{figure}[htbp]
        \centering
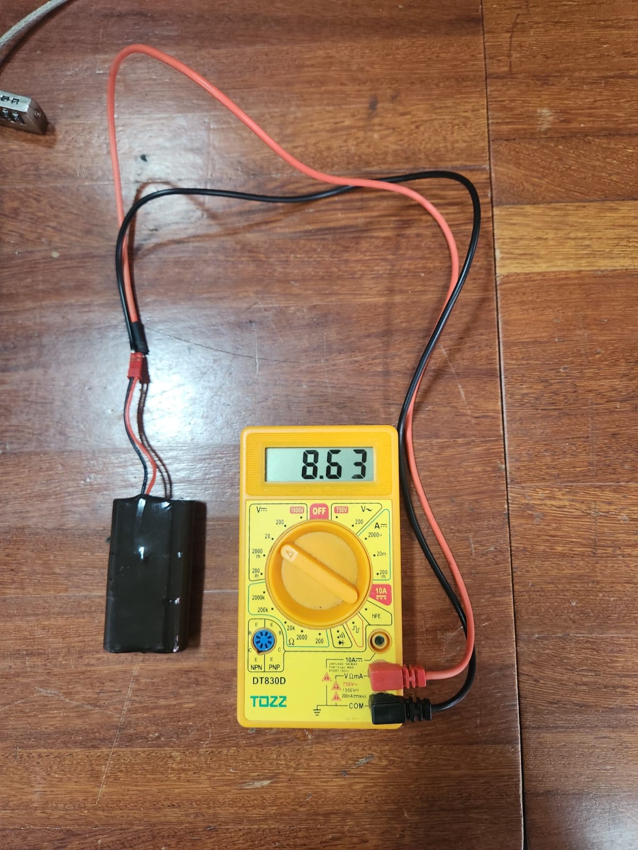
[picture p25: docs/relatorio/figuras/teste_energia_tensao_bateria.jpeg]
        
        \caption{Tensão da bateria em repouso.}
        \label{fig:Teste tensao bateria}
    \end{figure}

\subsection{Teste de autonomia cronometrada}

Neste teste, o objetivo foi avaliar a capacidade de fornecimento de energia da bateria aos componentes eletrônicos do sistema. Durante a execução, algumas limitações estiveram presentes: o terceiro sensor ToF ainda não havia sido entregue e um dos motores não foi acionado no ensaio principal. Além disso, a ESP32 foi alimentada externamente via USB, de forma a manter o controle sobre a leitura e transmissão dos dados dos sensores ao computador sem interferir na medição de autonomia da bateria. Os componentes efetivamente alimentados por ela ao longo do experimento foram os dois sensores ToF, o módulo INA219 e um motor DC. Na Figura \ref{fig:Teste energia integrado} é possível visualizar o cronômetro e os componentes eletrônicos em operação durante o ensaio de 18 minutos.

Paralelamente, a bateria foi cedida à equipe de eletrônica para testes individuais e combinados realizados com uma única carga completa. Nesses ensaios adicionais, foram acionados componentes além dos presentes no teste principal, incluindo os dois motores operando simultaneamente. O conjunto de testes realizados, ainda que sem operar todos os componentes de forma integrada em um único ensaio, fornece respaldo suficiente para a equipe confiar que a bateria suportará a carga total do sistema ao longo de uma corrida completa.

    \begin{figure}[htbp]
        \centering
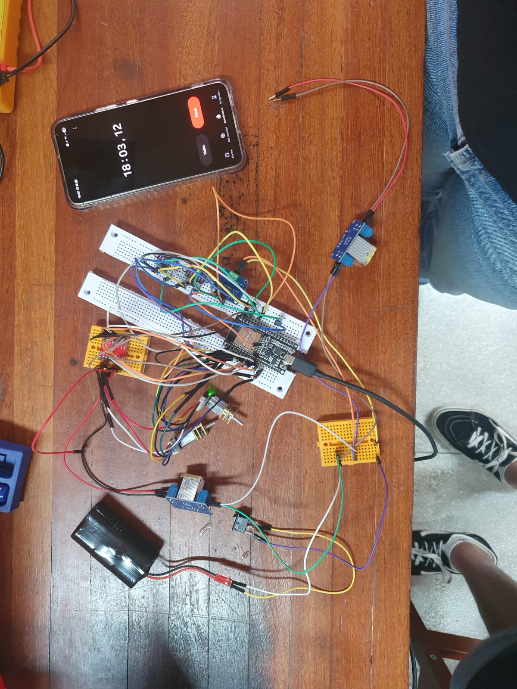
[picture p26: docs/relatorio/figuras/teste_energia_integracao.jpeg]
        
        \caption{Sistema integrado}
        \label{fig:Teste energia integrada}
    \end{figure}

\section{Testes de \textit{software}}

\subsection{Histórias de Usuário Implementadas}

Das várias histórias de usuário (HUs) mapeadas no \textit{backlog} do projeto no GitHub, boa parte de sua fundação estrutural já foi implementada e exaustivamente testada nesta fase. A Tabela \ref{tab:historias_usuario_implementadas} lista as HUs principais deste pacote e como elas se materializam no sistema.

\begin{figure}[H]
    \centering
    
    \caption{Execução de fluxos E2E no sistema.}
    \label{fig:placeholder}
\end{figure}

\begin{table}[H]
    \centering
    \caption{Histórias de Usuário Implementadas e Validadas}
    \label{tab:historias_usuario_implementadas}
    \begin{tabular}{|p{1.5cm}|p{6.5cm}|p{6cm}|}
        \hline
        \textbf{ID} & \textbf{Título da História} & \textbf{Validação / Interface} \\ \hline
        \textbf{HU 2.1.2} & Consumir telemetria do backend para acompanhar posição real & Dashboard: painel principal com representação matricial do robô. \\ \hline
        \textbf{HU 2.4} & Layout Adaptativo para Modo Alta Performance & Dashboard: botões de \textit{override} (Auto, Exploração, Alta Performance). \\ \hline
        \textbf{HU 3.1b} & Monitoramento Dinâmico da FSM & Dashboard: \textit{badge} dinâmico exibindo IDLE, MAPPING, etc. \\ \hline
        \textbf{HU 3.2} & Monitoramento de Tensão da Bateria & Dashboard: indicador numérico no \textit{header} com alerta crítico caso $V < 6.8$. \\ \hline
        \textbf{HU 3.5} & Plotagem em Tempo Real do Erro Direcional (PID) & Dashboard: gráficos reativos no painel de desempenho. \\ \hline
        \textbf{HU 3.6} & Alarme Imediato de Interrupção de Hardware & Dashboard: Modal \textit{pop-up} vermelho de ``Alarme Crítico''. \\ \hline
        \textbf{HU 4.1} & Gravação Contínua no InfluxDB & \textit{Backend}: fluxo UDP contínuo garantindo persistência. \\ \hline
        \textbf{HU 4.3} & Exportação de Histórico para Análise Externa & Página de Histórico: botão de \textit{Download CSV/JSON}. \\ \hline
        \textbf{HU 4.4} & Filtragem e Comparação de Desempenho por Pista & Dashboard: métricas de ``Volta Atual'' e ``Melhor Volta''. \\ \hline
        \textbf{HU 5.1.2} & Manter interface responsiva sem travamentos na queda de pacotes UDP & \textit{Frontend}: tratamento de jitter e tolerância a falhas na UI. \\ \hline
        \textbf{HU 6.1.2} & Validar propagação de pesos no simulador (Flood Fill) & \textit{Firmware}: Testes unitários com a biblioteca \textit{Catch2}. \\ \hline
    \end{tabular}
\end{table}

\subsection{Testes Unitários e Lógicos}

A equipe focou também em certificar a base lógica do robô, de forma isolada e em \textit{software}, para evitar problemas difíceis de depurar em hardware.

\subsubsection{Testes de Decodificação e Mapeamento (Backend)}
O módulo responsável por receber dados binários compactados no formato \textit{MessagePack} possui testes isolados no \textit{Jest}.
Foram validados pacotes corrompidos, decodificação correta de inteiros e valores em ponto flutuante, e tratativas de exceção (fallbacks de tempo) quando o robô envia métricas com chaves ausentes.

\begin{figure}[H]
    \centering
    % Cole a imagem do resultado do teste MsgPack com o nome abaixo:
    
    \caption{Resultado da execução dos testes unitários de decodificação e mapeamento dinâmico (MsgPack) no Node.js.}
    \label{fig:teste_msgpack}
\end{figure}

\subsubsection{Testes de Front-end}

Os testes unitários do Front-end foram implementados com \textbf{Vitest} e \textbf{Testing Library}, cobrindo componentes React e funções utilitárias de forma isolada, sem dependência de rede ou estado externo. O ambiente de execução utiliza \textit{jsdom} para simular o DOM do navegador em Node.js. O resultado geral dessa suíte pode ser observado na Figura~\ref{fig:teste-cobertura-front-geral}.

\begin{figure}[H]
    \centering
    
    \caption{Resultado geral dos testes unitários do Front-end.}
    \label{fig:teste-cobertura-front-geral}
\end{figure}

Com o objetivo de aumentar a testabilidade e garantir a pureza das funções, a lógica de manipulação da malha do labirinto foi recentemente refatorada. As funções foram extraídas do componente \texttt{HistoryPage.tsx} para o módulo utilitário independente \texttt{historyUtils.ts}. Foram implementados e validados 13 casos de teste focados nas operações primordiais desse módulo:
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

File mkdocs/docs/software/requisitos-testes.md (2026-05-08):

# Estruturação do Backlog (MoSCoW) e Roteiro de Testes
# **Requisitos de Backlog de Histórias de Usuário com Priorização MoSCoW**

Para a organização e priorização dos requisitos do sistema, foi utilizada a técnica MoSCoW (Must, Should, Could, Won’t), permitindo classificar funcionalidades de acordo com sua importância para o funcionamento do projeto.

As classificações utilizadas são:

- **Must Have:** requisitos obrigatórios para o funcionamento mínimo do sistema e atendimento dos critérios da disciplina;
- **Should Have:** requisitos importantes que agregam qualidade e robustez ao projeto;
- **Could Have:** funcionalidades desejáveis, mas não essenciais para a entrega principal;
- **Won’t Have / Wish:** funcionalidades fora do escopo atual do projeto.

## Histórias de Usuário

| ID | História de Usuário | Critério de Aceitação | MoSCoW | Explicação |
| --- | --- | --- | --- | --- |
| HU01 | Como desenvolvedor do sistema, quero visualizar o labirinto em tempo real para acompanhar o processo de exploração do Micromouse. | O mapa deve atualizar automaticamente em até 150 ms após o recebimento dos dados. | Must Have | A visualização em tempo real do labirinto é um requisito obrigatório da disciplina para apresentação da telemetria do robô. |
| HU02 | Como desenvolvedor, quero visualizar paredes detectadas dinamicamente para validar a leitura dos sensores do robô. | As paredes identificadas devem ser exibidas corretamente na interface conforme os dados recebidos. | Must Have | O sistema deve demonstrar o processo de mapeamento realizado pelo Micromouse durante a navegação. |
| HU03 | Como desenvolvedor, quero acompanhar posição, orientação e velocidade do robô para monitorar seu deslocamento no labirinto. | A interface deve exibir coordenadas, orientação e velocidade continuamente atualizadas. | Must Have | O monitoramento da movimentação do robô é necessário para validar o funcionamento da navegação autônoma. |
| HU04 | Como sistema, quero processar mensagens de telemetria de forma assíncrona para evitar bloqueios na interface. | O processamento não deve interromper a renderização visual durante o recebimento contínuo de dados. | Must Have | A interface deve permanecer responsiva mesmo durante transmissões constantes de telemetria. |
| HU05 | Como desenvolvedor, quero selecionar o tamanho do labirinto antes da execução para adequar a interface à arena física utilizada. | O sistema deve permitir configuração entre arenas 4×4, 8×8 e 16×16 antes do início da execução. | Must Have | Os três tamanhos de labirinto são explicitamente definidos nos requisitos da disciplina. |
| HU06 | Como desenvolvedor, quero validar a comunicação entre hardware e interface web para garantir funcionamento em condições reais. | Os testes devem confirmar transmissão contínua de dados sem perda significativa de pacotes. | Must Have | A comunicação entre o Micromouse e o sistema web é essencial para a telemetria em tempo real exigida no projeto. |
| HU07 | Como desenvolvedor, quero salvar trajetos e logs após a execução para posterior análise técnica. | O sistema deve persistir dados históricos em banco de dados após a conclusão da sessão. | Must Have | O armazenamento de dados após a execução é um requisito obrigatório descrito na especificação do projeto. |
| HU08 | Como desenvolvedor, quero consultar execuções anteriores para revisar trajetos e desempenho do robô. | O sistema deve permitir selecionar um labirinto específico ou visualizar dados de todos os labirintos. | Must Have | A consulta de execuções armazenadas faz parte dos requisitos de persistência definidos pela disciplina. |
| HU09 | Como desenvolvedor, quero exportar dados em JSON e CSV para elaborar relatórios técnicos e análises externas. | O sistema deve gerar arquivos válidos nos formatos JSON e CSV. | Should Have | A exportação facilita análises complementares e documentação do projeto. |
| HU10 | Como sistema, quero armazenar dados localmente em caso de falha de rede para evitar perda de telemetria. | Os dados devem permanecer salvos localmente até a reconexão com o servidor. | Should Have | O armazenamento temporário aumenta a robustez e confiabilidade do sistema. |
| HU11 | Como desenvolvedor, quero alternar entre modo exploração e modo alta performance para visualizar métricas adequadas ao contexto da execução. | O sistema deve alterar automaticamente os elementos visuais conforme o modo selecionado. | Should Have | Diferentes modos de visualização melhoram a análise durante exploração e corrida rápida. |
| HU12 | Como sistema, quero ajustar automaticamente a escala da grade visual conforme o tamanho do labirinto selecionado. | As dimensões e coordenadas da interface devem ser recalculadas automaticamente. | Should Have | O ajuste automático melhora a adaptação visual entre diferentes arenas. |
| HU13 | Como desenvolvedor, quero visualizar áreas ainda não exploradas para facilitar o acompanhamento da exploração do labirinto. | A interface deve diferenciar visualmente células exploradas e não exploradas. | Should Have | A distinção visual facilita a análise do algoritmo de exploração. |
| HU14 | Como desenvolvedor, quero visualizar consumo energético em tempo real para monitorar o uso da bateria do robô. | O sistema deve exibir tensão e corrente continuamente atualizadas. | Must Have | O monitoramento energético auxilia análises de eficiência, mas não é essencial para a entrega mínima. |
| HU15 | Como desenvolvedor, quero comparar o mapa gerado com a planta física do labirinto para medir a precisão do mapeamento. | O sistema deve calcular a margem de erro do mapeamento após os testes. | Must Have | A funcionalidade auxilia validações avançadas do algoritmo de navegação. |
| HU16 | Como desenvolvedor, quero visualizar velocímetro e cronômetro ampliados durante o modo de alta performance. | O sistema deve priorizar a exibição de velocidade e tempo durante corridas rápidas. | Must Have | A funcionalidade melhora a experiência visual durante testes de desempenho. |
| HU17 | Como sistema, quero registrar cronologicamente eventos e decisões do algoritmo para facilitar depuração futura. | Os eventos devem ser armazenados em ordem temporal no histórico da execução. | Could Have | O registro detalhado auxilia manutenção e análise do comportamento do robô. |
| HU18 | Como desenvolvedor, quero visualizar quando o Micromouse alcançar a área objetivo para confirmar a conclusão do desafio. | O Micromouse deve apresentar no dashboard que chegou no objetivo, assim que conseguir, o cronômetro deve parar. | Must Have | O robô deve utilizar os sensores e o algoritmo de navegação para explorar o labirinto e alcançar automaticamente a região central. |

# Requisitos Não Funcionais

| ID | Requisito Não Funcional | Métrica Objetiva |
| --- | --- | --- |
| RNF01 | O sistema deve atualizar a interface web em até 150 ms após a captura dos dados pelo microcontrolador. | Tempo máximo de atualização ≤ 150 ms. |
| RNF02 | O sistema deve suportar processamento assíncrono de mensagens de telemetria. | A interface não pode congelar durante recepção contínua de dados. |
| RNF03 | O sistema deve suportar arenas nos tamanhos 4×4, 8×8 e 16×16. | Os três formatos devem ser configuráveis antes da execução. |
| RNF04 | O sistema deve persistir trajetos, tempos e logs após cada execução. | Os dados devem permanecer disponíveis para consulta posterior. |
| RNF05 | O sistema deve permitir consulta de sessões históricas em até 3 segundos. | Tempo máximo de resposta ≤ 3 s. |
| RNF06 | O sistema deve permitir exportação válida em JSON e CSV. | Os arquivos exportados devem seguir corretamente os respectivos formatos. |
| RNF07 | O sistema deve manter sincronização contínua entre hardware e interface web. | Taxa de perda de pacotes críticos inferior a 1%. |
| RNF08 | O sistema deve armazenar telemetria localmente durante falhas temporárias de conexão. | Nenhum dado deve ser perdido durante desconexões inferiores a 5 minutos. |

# Roteiro de Testes Funcionais

| ID | Objetivo | Pré-condições | Procedimento | Resultado Esperado |
| --- | --- | --- | --- | --- |
| TF01 | Validar renderização do labirinto em tempo real | Sistema conectado ao Micromouse | Iniciar telemetria e movimentar o robô | O mapa deve atualizar em até 150 ms |
| TF02 | Validar deteção de paredes | Sensores operacionais | Aproximar o robô das paredes do labirinto | As paredes devem ser exibidas corretamente |
| TF03 | Validar atualização da posição e orientação do robô | Sensores de localização operacionais | Movimentar o robô em diferentes direções | Coordenadas e orientação devem ser atualizadas corretamente |
| TF04 | Validar configuração do tamanho do labirinto | Sistema inicializado | Selecionar arenas 4×4, 8×8 e 16×16 | A grade visual deve ser redimensionada corretamente |
| TF05 | Validar comunicação entre hardware e interface web | Sistema completo em operação | Executar telemetria contínua | Não deve haver perda significativa de pacotes |
| TF06 | Validar persistência dos dados da execução | Sessão concluída | Encerrar execução do robô | Logs, trajetos e métricas devem ser salvos no banco |
| TF07 | Validar consulta de execuções anteriores | Banco de dados populado | Consultar sessões armazenadas | Os dados devem ser exibidos corretamente |
| TF08 | Validar exportação de dados | Histórico disponível | Solicitar exportação dos dados | Arquivos JSON e CSV válidos devem ser gerados |
| TF09 | Validar troca entre modos de operação | Sistema em execução | Alternar entre modo exploração e alta performance | A interface deve alterar os elementos exibidos |
| TF10 | Validar persistência local em falha de rede | Telemetria ativa | Desconectar temporariamente a rede | Os dados devem permanecer armazenados localmente |
| TF11 | Validar sincronização após reconexão | Cache local preenchido | Reconectar o sistema à rede | Os dados pendentes devem ser enviados ao servidor |
| TF12 | Validar monitorização energética | Sensores de tensão e corrente conectados | Executar movimentação do robô | Valores energéticos devem ser exibidos corretamente |
| TF13 | Validar diferenciação de áreas desconhecidas | Labirinto parcialmente explorado | Executar exploração parcial do labirinto | Áreas não exploradas devem possuir destaque visual |
| TF14 | Validar processamento assíncrono | Fluxo intenso de telemetria | Enviar múltiplos pacotes simultaneamente | A interface deve permanecer responsiva |

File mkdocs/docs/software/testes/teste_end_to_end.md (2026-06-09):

# Testes End-to-End (E2E)

## O que são

Testes End-to-End (E2E) simulam um **usuário real interagindo com a aplicação completa** no navegador. Diferente dos unitários e de integração, aqui o frontend, o backend simulador e o websocket de telemetria rodam de verdade — sem mocks, exceto quando necessário para isolar APIs externas específicas.

Neste projeto, usamos [Playwright](https://playwright.dev/) para testes E2E.

| Localização | Framework | Browser |
|---|---|---|
| `src/frontend/__tests__/e2e/` | Playwright 1.60 | Chromium |

---

## Estrutura

```
src/frontend/
├── __tests__/e2e/
│   ├── navegacao.spec.ts        ← Testes de navegação entre páginas
│   ├── dashboard.spec.ts        ← Testes do Dashboard (telemetria, modos, alertas)
│   └── historico.spec.ts        ← Testes da página de Histórico (replay, upload)
├── playwright.config.ts         ← Configuração do Playwright
└── package.json
```

---

## Configuração (`playwright.config.ts`)

| Parâmetro | Valor | Descrição |
|---|---|---|
| `testDir` | `./__tests__/e2e` | Diretório dos testes |
| `timeout` | 30s | Tempo máximo por teste |
| `expect.timeout` | 5s | Timeout de assertions |
| `fullyParallel` | `true` | Execução paralela |
| `retries` | 0 (local) / 2 (CI) | Retentativas em caso de falha |
| `workers` | 1 | Um worker por vez |
| `reporter` | `html` | Relatório HTML |
| `trace` | `on-first-retry` | Grava trace apenas no retry |
| `video` | `retain-on-failure` | Vídeo só quando falha |
| `baseURL` | `http://127.0.0.1:5173` | URL base da aplicação |
| `webServer.command` | `npm run dev -- --host 127.0.0.1 --port 5173` | Inicia o servidor Vite automaticamente |
| `webServer.timeout` | 120s | Timeout para o servidor subir |

---

## Testes de Navegação (`navegacao.spec.ts`)

Testa a estrutura básica de navegação da aplicação — sidebar, links e troca de páginas.

### Casos de teste

#### 1. Sidebar contém links para Dashboard e Histórico

| Verificação |
|---|
| Link "Dashboard" existe e está visível na sidebar |
| Link "Histórico" existe e está visível na sidebar |

#### 2. Navegação entre páginas

| Passo | Verificação |
|---|---|
| Clique em "Histórico" | URL muda para `/historico` |
| Clique em "Dashboard" | URL volta para `/` |

#### 3. Status de conexão

| Verificação |
|---|
| Ícone WiFi visível na interface |
| Cor do ícone indica status (verde = conectado, âmbar = desconectado) |
| Texto "Conectado" visível quando há conexão |

---

## Testes do Dashboard (`dashboard.spec.ts`)

Testa a tela principal de telemetria do robô, incluindo métricas em tempo real, modos de operação e alertas críticos. **Usa o simulador real com websocket** — sem mocks de telemetria.

### Casos de teste

#### 1. Métricas iniciais

| Métrica | Validação |
|---|---|
| Tensão da Bateria | Exibida com formato `XX.XV` (regex `\d+\.\d+V`) |
| Velocidade | Valor visível |
| Posição Atual | Coordenadas visíveis |
| Estado do Robô | String do estado FSM visível |

#### 2. Alternar modos de override

O dashboard permite alternar entre modos manuais de operação:

| Modo | Comportamento esperado |
|---|---|
| **Auto** | Robô opera automaticamente com algoritmo de exploração |
| **Exploração** | Métricas específicas de exploração aparecem (posição, paredes detectadas) |
| **Alta Performance** | Trajeto rápido (FAST_RUN) exibido com pontos verdes no grid |

**Verificação**: Ao alternar entre modos, diferentes conjuntos de métricas aparecem/desaparecem conforme o modo selecionado.

#### 3. Telemetria em tempo real (simulação)

| Verificação |
|---|
| Posição do robô atualiza automaticamente |
| Timestamp da última atualização muda ao longo do tempo |
| Célula do robô visível no grid do labirinto |

#### 4. Alerta crítico de bateria (tensão < 6.8V)

| Condição | Comportamento |
|---|---|
| Tensão cai abaixo de 6.8V | Alerta crítico de bateria aparece na tela |
| Timeout do teste | 25 segundos (aguarda o simulador emitir o estado) |

#### 5. Erro de hardware (estado = ERROR)

| Condição | Comportamento |
|---|---|
| Robô entra em estado ERROR | Alarme de hardware crítico visível |
| | Mensagem de parada de emergência exibida |
| Timeout do teste | 30 segundos |

#### 6. Gaveta de logs

| Ação | Verificação |
|---|---|
| Abrir gaveta (botão toggle) | Logs ficam visíveis |
| Fechar gaveta | Logs são ocultados |
| Conteúdo | Mensagens de log apropriadas ao contexto |

#### 7. Trajeto rápido (FAST_RUN)

| Condição | Verificação |
|---|---|
| Modo Alta Performance ativo | Pontos verdes (trajetória FAST_RUN) visíveis no grid |

---

## Testes do Histórico (`historico.spec.ts`)

Testa a página de histórico de corridas — listagem, carregamento, replay passo a passo e upload de arquivos.

### Estratégia de mock

Diferente do Dashboard (que usa simulador real), os testes de Histórico **interceptam chamadas HTTP** via `page.route()` para simular respostas da API de arquivos JSON sem depender de arquivos reais no disco.

#### Mock da listagem (`GET /api/maze_runs`)

```ts
await page.route('**/api/maze_runs', (route) => {
  if (route.request().method() === 'GET' && !route.request().url().includes('corrida')) {
    route.fulfill({
      status: 200,
      body: JSON.stringify(['corrida_2024.json', 'corrida_2025.json'])
    });
  } else {
    route.continue();
  }
});
```

#### Mock dos detalhes (`GET /api/maze_runs/:arquivo`)

```ts
const MOCK_HISTORICO = {
  id_corrida: 'run_001',
  historico: [
    { x: 0, y: 7, orientacao: 'NORTE', paredes: [] },
    { x: 0, y: 6, orientacao: 'NORTE', paredes: [{ x: 0, y: 6, dir: 'NORTE' }] },
    { x: 0, y: 5, orientacao: 'NORTE', paredes: [] },
    { x: 1, y: 5, orientacao: 'LESTE', paredes: [{ x: 1, y: 5, dir: 'LESTE' }] },
    { x: 2, y: 5, orientacao: 'LESTE', paredes: [] },
    { x: 3, y: 5, orientacao: 'LESTE', paredes: [] }
  ]
};
```

### Casos de teste

#### 1. Carregar lista de corridas

| Verificação |
|---|
| Lista de arquivos exibida na tela |
| Contagem de corridas visível |
| Cada arquivo tem um botão associado |

#### 2. Carregar detalhes ao clicar

| Ação | Verificação |
|---|---|
| Clique em uma corrida | Detalhes da corrida carregados e exibidos |
| | Informações do passo atual visíveis (x, y, orientacao) |

#### 3. Navegação passo a passo

| Botão | Verificação |
|---|---|
| ▶ (Avançar) | Posição muda de (0,7) → (0,6) |
| ◀ (Voltar) | Posição volta para (0,7) |
| ⏮ (Reset) | Volta ao passo 1 de 6 |

#### 4. Replay automático

| Ação | Verificação |
|---|---|
| Pressionar Play (▶▶) | Passos avançam automaticamente |
| | Navega por múltiplos passos sem intervenção manual |
| Timeout | 1.5 segundos para progressão automática |

#### 5. Reset para o início

| Verificação |
|---|
| Após avançar vários passos, reset volta ao passo 1 |
| Indicador "1/6" visível após reset |

#### 6. Upload de arquivo JSON

| Ação | Verificação |
|---|---|
| Selecionar arquivo `.json` | Arquivo carregado e processado |
| Arquivo com formato `{historico: [...]}` | Passos extraídos e replay disponível |

#### 7. Controle de velocidade

| Controle | Verificação |
|---|---|
| Velocidade 10× | Replay avança mais rápido |
| Mudança de velocidade | Progressão visivelmente alterada |

---

## Como rodar

```bash
cd src/frontend
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

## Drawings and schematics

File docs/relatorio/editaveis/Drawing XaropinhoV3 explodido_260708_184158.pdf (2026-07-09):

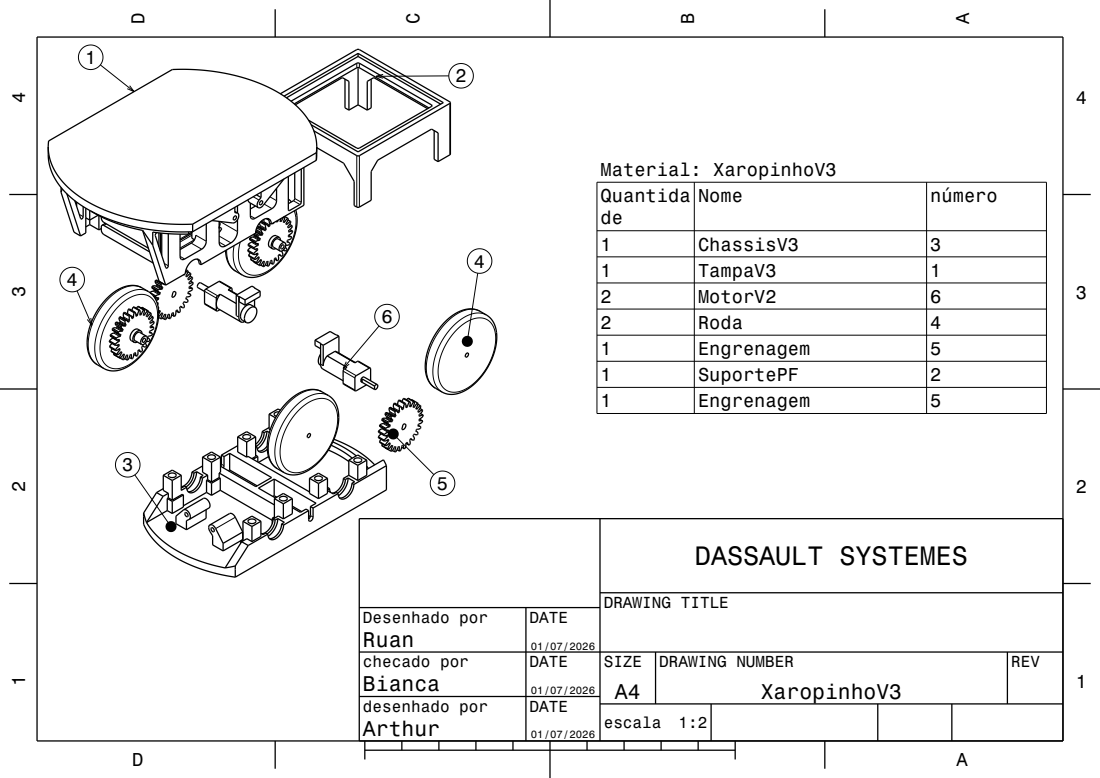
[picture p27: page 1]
DRAWING TITLE; DASSAULT SYSTEMES; Material: XaropinhoV3

Quantida de | Nome | número

1 | ChassisV3 | 3
1 | TampaV3 | 1
2 | MotorV2 | 6
2 | Roda | 4
1 | Engrenagem | 5
1 | SuportePF | 2

Desenhado por Ruan | DATE 01/07/2026

checado por Bianca | DATE 01/07/2026 | SIZE A4 | DRAWING NUMBER XaropinhoV3 | REV

desenhado por Arthur | DATE 01/07/2026

escala 1:2

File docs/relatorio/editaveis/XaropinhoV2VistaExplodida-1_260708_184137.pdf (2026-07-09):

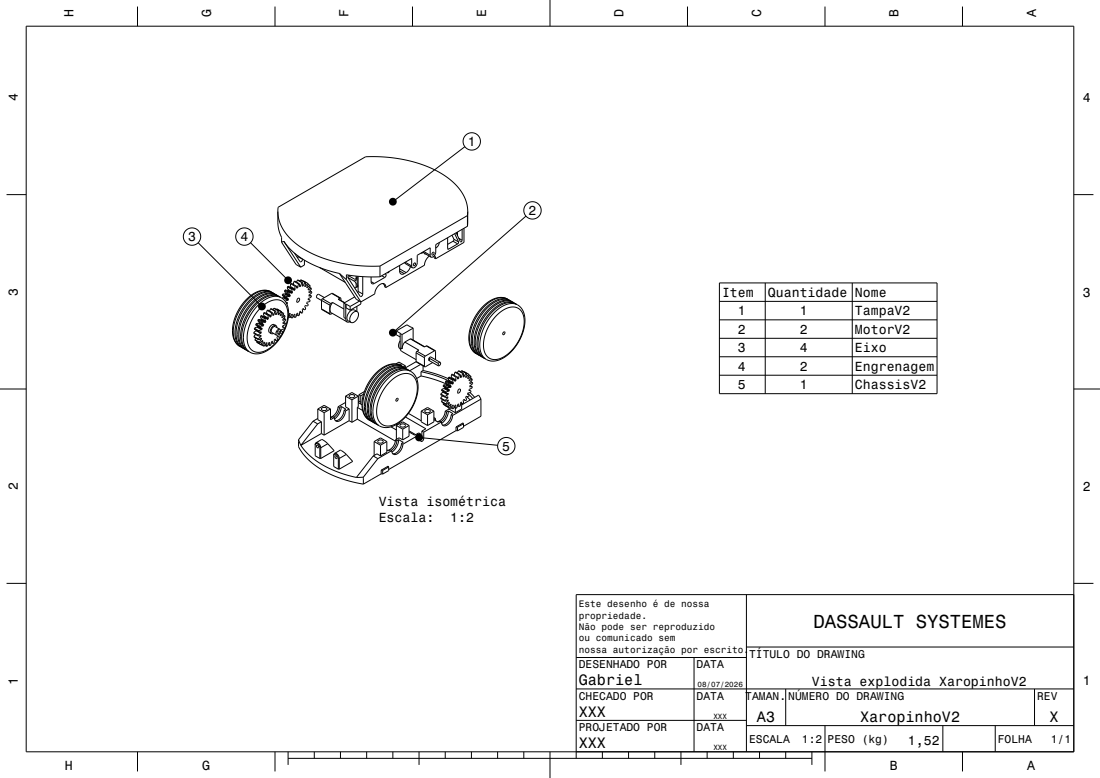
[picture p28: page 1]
DASSAULT SYSTEMES; Vista explodida XaropinhoV2; Vista isométrica Escala: 1:2

Item | Quantidade | Nome
1 | 1 | TampaV2
2 | 2 | MotorV2
3 | 4 | Eixo
4 | 2 | Engrenagem
5 | 1 | ChassisV2

Este desenho é de nossa
propriedade.
Não pode ser reproduzido
ou comunicado sem
nossa autorização por escrito.

TÍTULO DO DRAWING

DESENHADO POR Gabriel | DATA 08/07/2026
CHECADO POR XXX | DATA XXX | TAMAN. A3 | NÚMERO DO DRAWING XaropinhoV2 | REV X
PROJETADO POR XXX | DATA XXX

ESCALA 1:2 | PESO (kg) 1,52 | FOLHA 1/1

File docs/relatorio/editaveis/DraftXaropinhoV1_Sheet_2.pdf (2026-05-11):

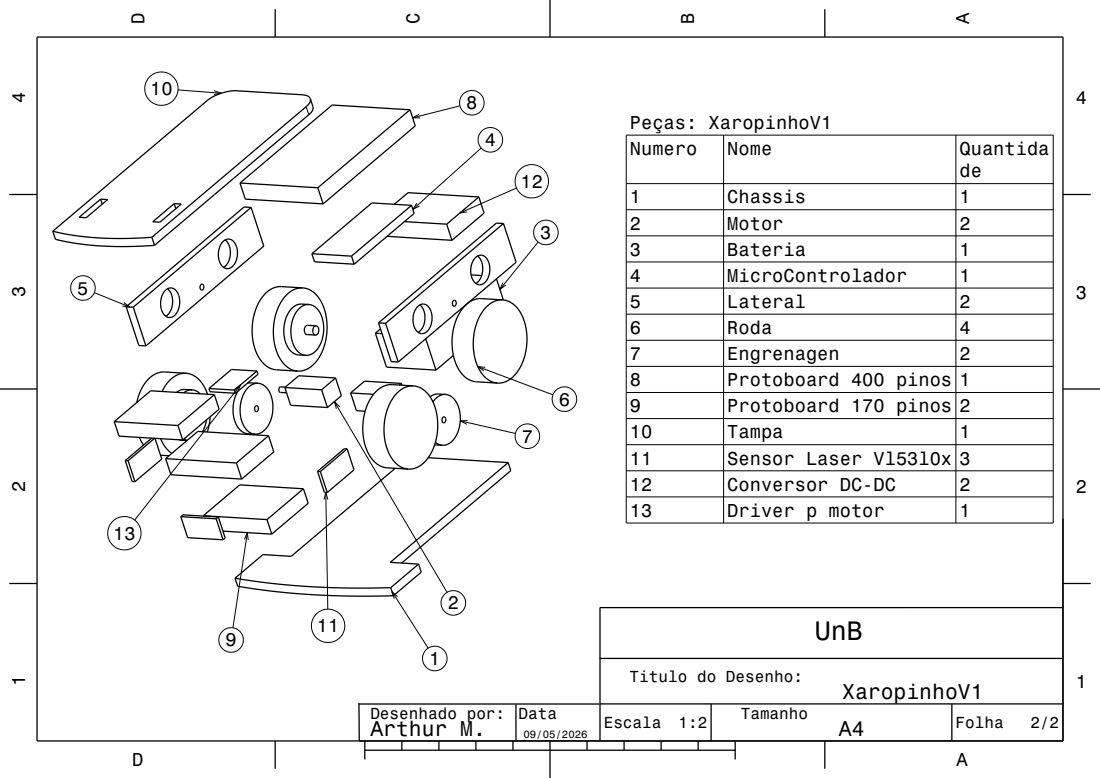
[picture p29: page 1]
Desenhado por: Arthur M.; Escala 1:2; Folha Tamanho; Peças: XaropinhoV1

Numero | Nome | Quantida de

1 | Chassis | 1
2 | Motor | 2
3 | Bateria | 1
4 | MicroControlador | 1
5 | Lateral | 2
6 | Roda | 4
7 | Engrenagen | 2
8 | Protoboard 400 pinos | 1
9 | Protoboard 170 pinos | 2
10 | Tampa | 1
11 | Sensor Laser Vl53l0x | 3
12 | Conversor DC-DC | 2
13 | Driver p motor | 1

Titulo do Desenho:

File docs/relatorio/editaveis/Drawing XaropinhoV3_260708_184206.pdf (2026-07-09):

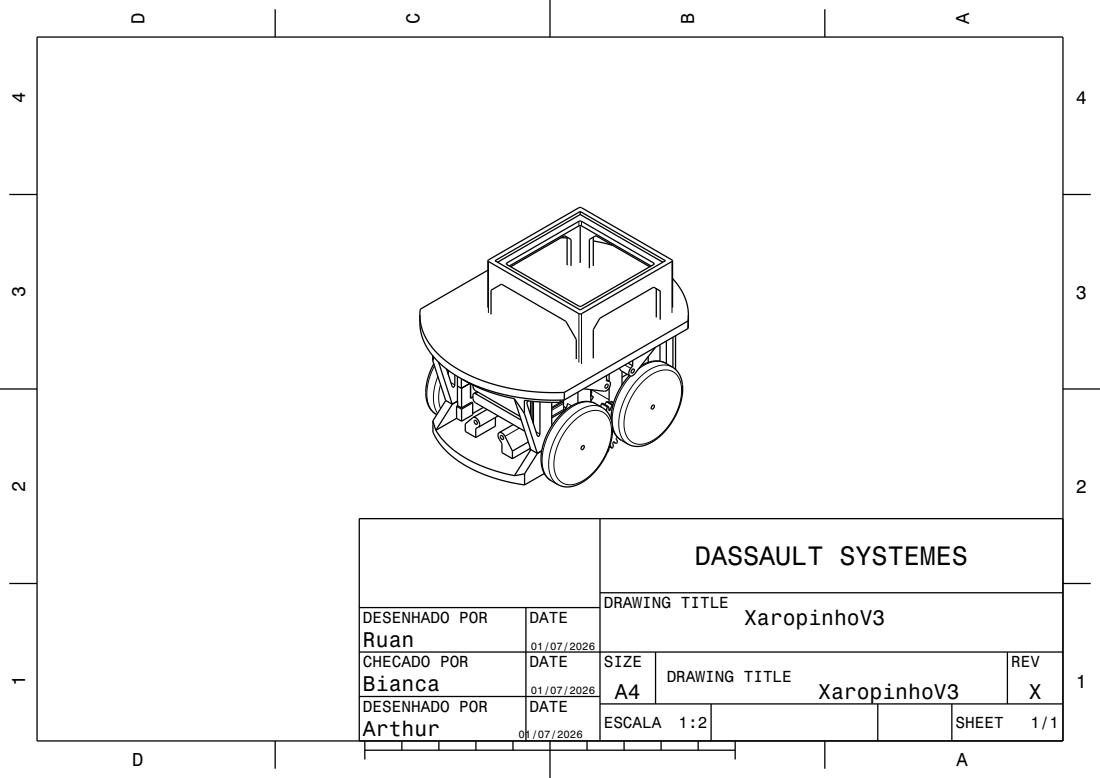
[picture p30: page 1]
XaropinhoV3; DRAWING TITLE; DASSAULT SYSTEMES

DESENHADO POR Ruan | DATE 01/07/2026

CHECADO POR Bianca | DATE 01/07/2026 | SIZE A4 | DRAWING TITLE XaropinhoV3 | REV X

DESENHADO POR Arthur 01/07/2026 | DATE

ESCALA 1:2 | SHEET 1/1

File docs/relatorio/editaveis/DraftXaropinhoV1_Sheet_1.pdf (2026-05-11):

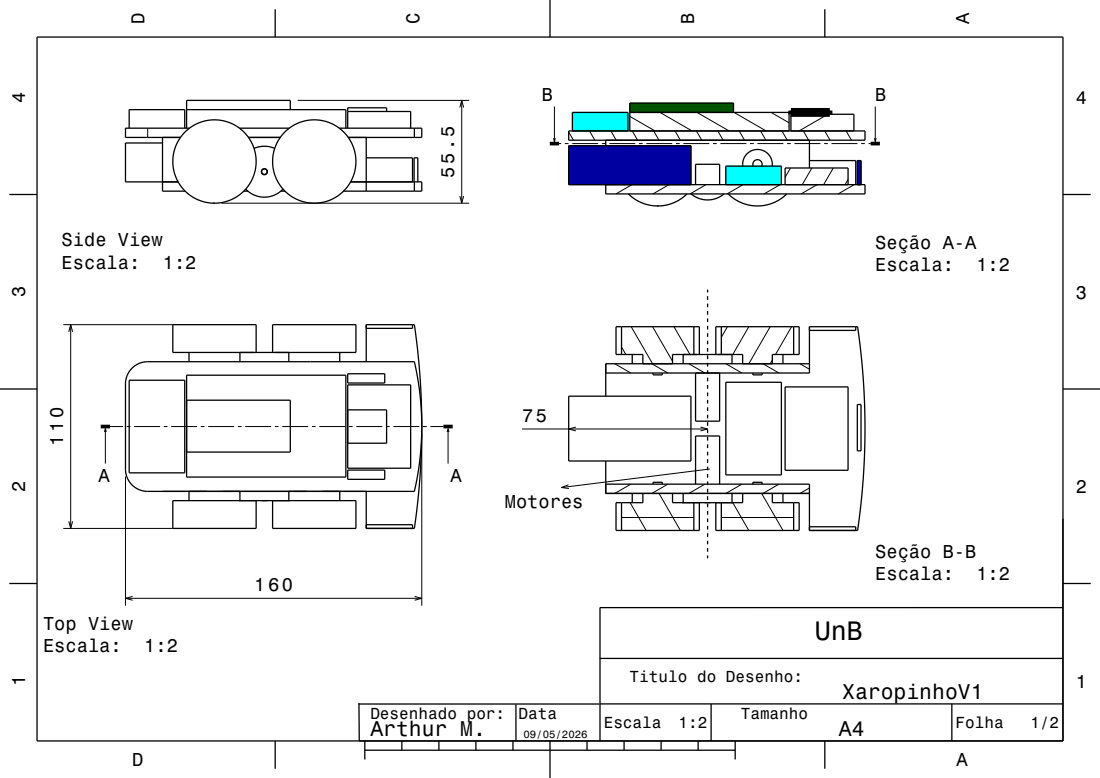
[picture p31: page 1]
Desenhado por: Arthur M.; Escala 1:2; Folha; 1/2 Tamanho; Top View Escala: 1:2; Seção A-A Escala: 1:2; Seção B-B Escala: 1:2; Side View Escala: 1:2

Titulo do Desenho:

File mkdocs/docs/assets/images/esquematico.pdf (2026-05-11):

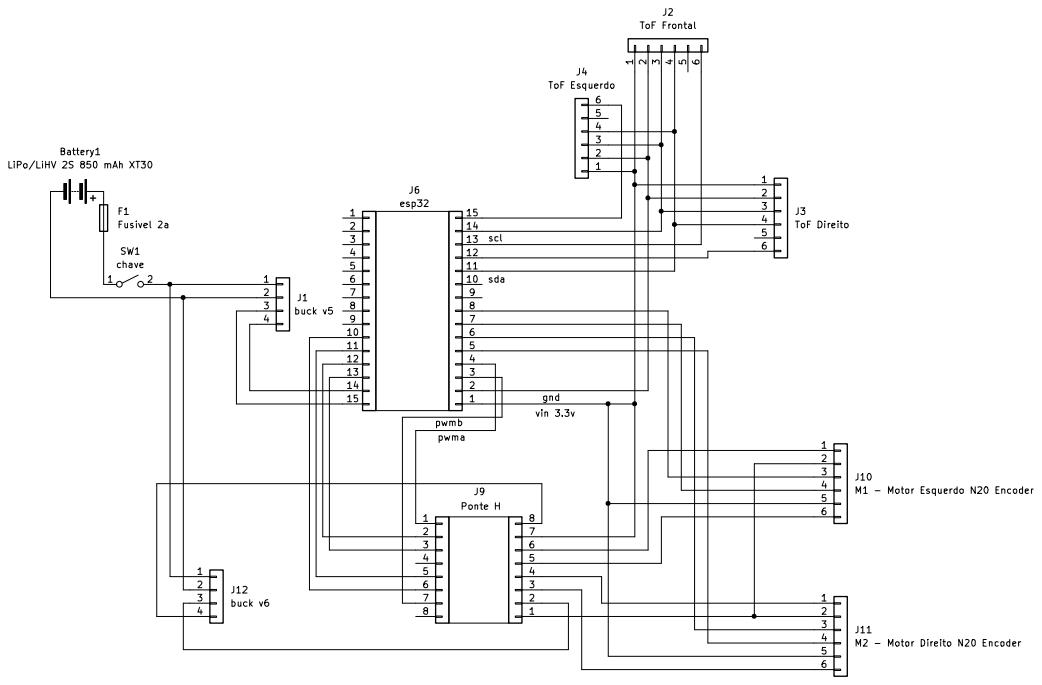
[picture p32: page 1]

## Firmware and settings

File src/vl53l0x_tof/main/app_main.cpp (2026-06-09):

#include "VL53L0X.h"

#include "driver/gpio.h"
#include "driver/i2c.h"
#include "esp_log.h"
#include "freertos/FreeRTOS.h"
#include "freertos/task.h"

namespace {
constexpr const char *TAG = "VL53L0X_TOF";

constexpr i2c_port_t kI2cPort = I2C_NUM_0;
constexpr gpio_num_t kSdaPin = GPIO_NUM_21;
constexpr gpio_num_t kSclPin = GPIO_NUM_22;
constexpr uint32_t kI2cFreqHz = 400000;

constexpr float kRegA = 0.9951f;
constexpr float kRegB_cm = 1.7475f;

constexpr float kFiltroAlpha = 0.5f;

float corrigirDistanciaMm(uint16_t distancia_raw_mm) {
    float distancia_raw_cm = static_cast<float>(distancia_raw_mm) / 10.0f;

    float distancia_corrigida_cm =
        (distancia_raw_cm - kRegB_cm) / kRegA;

    return distancia_corrigida_cm * 10.0f;
}

constexpr gpio_num_t kXshutPin = GPIO_NUM_MAX;

constexpr TickType_t kReadPeriod = pdMS_TO_TICKS(200);

void halt_task() {
  while (true) {
    vTaskDelay(portMAX_DELAY);
  }
}
}  // namespace

extern "C" void app_main(void) {
  ESP_LOGI(TAG, "Inicializando VL53L0X em I2C%d SDA=%d SCL=%d",
           static_cast<int>(kI2cPort), static_cast<int>(kSdaPin),
           static_cast<int>(kSclPin));

  VL53L0X tof(kI2cPort, kXshutPin);
  tof.i2cMasterInit(kSdaPin, kSclPin, kI2cFreqHz);

  if (!tof.init()) {
    ESP_LOGE(TAG, "Falha ao inicializar VL53L0X no endereco padrao 0x29");
    halt_task();
  }

  ESP_LOGI(TAG, "VL53L0X pronto. Iniciando leituras.");
/*
  while (true) {
    uint16_t distance_mm = 0;
    TickType_t start_tick = xTaskGetTickCount();
    bool ok = tof.read(&distance_mm);
    TickType_t end_tick = xTaskGetTickCount();
    int took_ms = static_cast<int>((end_tick - start_tick) * portTICK_PERIOD_MS);

    if (ok) {
      ESP_LOGI(TAG, "distancia=%u mm leitura=%d ms", (static_cast<float>(distance_mm)-1.7475)/0.9951, took_ms);
    } else {
      ESP_LOGE(TAG, "falha na leitura leitura=%d ms", took_ms);
    }

    vTaskDelay(kReadPeriod);
  }
*/

float distancia_filtrada_mm = 0.0f;
bool filtro_iniciado = false;

while (true) {
    uint16_t distance_mm = 0;

    TickType_t start_tick = xTaskGetTickCount();
    bool ok = tof.read(&distance_mm);
    TickType_t end_tick = xTaskGetTickCount();

    int took_ms = static_cast<int>((end_tick - start_tick) * portTICK_PERIOD_MS);

    if (ok) {
        float distancia_corrigida_mm = corrigirDistanciaMm(distance_mm);

        if (!filtro_iniciado) {
            distancia_filtrada_mm = distancia_corrigida_mm;
            filtro_iniciado = true;
        } else {
            distancia_filtrada_mm =
                (1.0f - kFiltroAlpha) * distancia_filtrada_mm +
                kFiltroAlpha * distancia_corrigida_mm;
        }

        ESP_LOGI(TAG,
                 "raw=%u mm corrigida=%.2f mm filtrada=%.2f mm leitura=%d ms",
                 distance_mm,
                 distancia_corrigida_mm,
                 distancia_filtrada_mm,
                 took_ms);
    } else {
        ESP_LOGE(TAG, "falha na leitura leitura=%d ms", took_ms);
    }

    vTaskDelay(kReadPeriod);
}



}

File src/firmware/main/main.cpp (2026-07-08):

#include <stdio.h>
#include "freertos/FreeRTOS.h"
#include "freertos/task.h"
#include "movement.hpp"
#include "telemetry.hpp"
#include "tof_sensor.hpp"
#include "wifi_manager.hpp"

// Task para simulação de instabilidade de rede (Validação do Ring Buffer)
// void TaskSimularQuedaRede(void *pvParameters) {
//     for (;;) {
//         vTaskDelay(pdMS_TO_TICKS(15000)); // Período de operação normal
//         
//         printf("\n[DIAGNOSTICO] Simulando queda de conectividade Wi-Fi (15s)...\n");
//         wifi_conectado = false; // Interrompe conectividade lógica para forçar acúmulo no buffer offline
//         
//         vTaskDelay(pdMS_TO_TICKS(15000)); // Período offline simulado
//         
//         printf("\n[DIAGNOSTICO] Conectividade restabelecida. Acionando descarregamento em lote.\n");
//         wifi_conectado = true; // Restabelecimento da conexão
//     }
// }

extern "C" void app_main(void) {
    printf("Iniciando Micromouse Modular com FreeRTOS... \n");


    // inicializar wi fi
    wifi_init_sta();
    // 1. Inicializa a Fila global definida em telemetry.hpp
    FilaTelemetria = xQueueCreate(10, sizeof(PacoteTelemetria));
    if (FilaTelemetria == NULL) {
        printf("Falha ao criar a Fila de Telemetria!\n");
        return;
    }

    // 2. Cria a tarefa de leitura do sensor ToF no Core 0
    xTaskCreatePinnedToCore(
        ToFTask,
        "TOF_Core0",
        4096,
        NULL,
        6,
        NULL,
        0
    );

    // 3. Fixação da tarefa de controle motor e PID no Core 0 (alta prioridade) para garantir determinismo de tempo real.
    xTaskCreatePinnedToCore(
        MoveTask,            // Função executada
        "Movement_Core0",    // Nome para debug
        4096,                // Stack size
        NULL,                // Sem argumentos
        5,                   // Prioridade
        NULL,                // Sem task handle
        0                    // Executa no Core 0
    );
    
    // 4. Isolamento da carga de rede (Wi-Fi/UDP) no Core 1 para evitar jitter no loop de controle do Core 0.
    xTaskCreatePinnedToCore(
        TaskTelemetria,
        "Telemetry_core1",
        8192,
        NULL,
        5,
        NULL,
        1                    // Executa no Core 1
    );

    // 5. Cria a tarefa de simulação de conectividade instável
    /* xTaskCreate(
        TaskSimularQuedaRede,
        "   ",
        2048,
        NULL,
        2,                   // Prioridade mais baixa
        NULL
    ); */
}

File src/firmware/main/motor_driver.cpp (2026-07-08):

#include "motor_driver.hpp"
#include "driver/ledc.h"
#include "driver/gpio.h"
#include <cmath>

// --- Configurações Físicas do L298N ---

// Motor Esquerdo (Lado B do L298N)
constexpr gpio_num_t PIN_MOTOR_L_IN3 = GPIO_NUM_25; // Direção 1 (IN3)
constexpr gpio_num_t PIN_MOTOR_L_IN4 = GPIO_NUM_32; // Direção 2 (IN4)
constexpr gpio_num_t PIN_MOTOR_L_PWM = GPIO_NUM_33; // Velocidade (ENB)

// Motor Direito (Lado A do L298N)
constexpr gpio_num_t PIN_MOTOR_R_IN1 = GPIO_NUM_26; // Direção 1 (IN1)
constexpr gpio_num_t PIN_MOTOR_R_IN2 = GPIO_NUM_27; // Direção 2 (IN2)
constexpr gpio_num_t PIN_MOTOR_R_PWM = GPIO_NUM_14; // Velocidade (ENA)

// Configurações do PWM (LEDC) do ESP32
constexpr ledc_timer_t PWM_TIMER           = LEDC_TIMER_0;
constexpr ledc_mode_t PWM_MODE             = LEDC_HIGH_SPEED_MODE;
constexpr ledc_channel_t PWM_CHANNEL_LEFT  = LEDC_CHANNEL_0;
constexpr ledc_channel_t PWM_CHANNEL_RIGHT = LEDC_CHANNEL_1;
constexpr ledc_timer_bit_t PWM_RESOLUTION  = LEDC_TIMER_8_BIT; // 8 bits = 0 a 255
constexpr uint32_t PWM_FREQUENCY_HZ        = 1000; // Frequência de 1kHz: Pode gerar ruído audível no motor, mas maximiza o torque em baixas velocidades.

void motor_init() {
    // 1. Configurar os pinos de direção como saída (OUTPUT)
    uint64_t dir_pins_mask = (1ULL << PIN_MOTOR_L_IN3) | (1ULL << PIN_MOTOR_L_IN4) |
                             (1ULL << PIN_MOTOR_R_IN1) | (1ULL << PIN_MOTOR_R_IN2);

    gpio_config_t io_conf = {
        .pin_bit_mask = dir_pins_mask,
        .mode = GPIO_MODE_OUTPUT,
        .pull_up_en = GPIO_PULLUP_DISABLE,
        .pull_down_en = GPIO_PULLDOWN_DISABLE,
        .intr_type = GPIO_INTR_DISABLE
    };
    gpio_config(&io_conf);

    // Configurar pino de ENABLE (se aplicável)
    if (PIN_MOTOR_ENABLE != GPIO_NUM_MAX) {
        gpio_set_direction((gpio_num_t)PIN_MOTOR_ENABLE, GPIO_MODE_OUTPUT);
        gpio_set_level((gpio_num_t)PIN_MOTOR_ENABLE, 1); // Liga a ponte H
    }


    // 2. Configurar o Timer do PWM (Comum para os dois motores)
    ledc_timer_config_t timer_conf = {
        .speed_mode       = PWM_MODE,
        .duty_resolution  = PWM_RESOLUTION,
        .timer_num        = PWM_TIMER,
        .freq_hz          = PWM_FREQUENCY_HZ,
        .clk_cfg          = LEDC_AUTO_CLK
    };
    ledc_timer_config(&timer_conf);

    // 3. Configurar os Canais PWM (Um para cada motor)
    ledc_channel_config_t channel_conf_left = {
        .gpio_num       = PIN_MOTOR_L_PWM,
        .speed_mode     = PWM_MODE,
        .channel        = PWM_CHANNEL_LEFT,
        .intr_type      = LEDC_INTR_DISABLE,
        .timer_sel      = PWM_TIMER,
        .duty           = 0, // Começa parado
        .hpoint         = 0
    };
    ledc_channel_config(&channel_conf_left);

    ledc_channel_config_t channel_conf_right = channel_conf_left; // Reaproveita configuração base
    channel_conf_right.gpio_num = PIN_MOTOR_R_PWM;
    channel_conf_right.channel  = PWM_CHANNEL_RIGHT;
    ledc_channel_config(&channel_conf_right);
}

// Lógica da Ponte H (L298N): Determina o sentido de corrente (Forward/Reverse) via pinos lógicos IN 
// e modula a potência via Duty Cycle (Sinal PWM) no pino EN.
void motor_set_speed(MotorSide side, int pwm_value) {
    // Garantimos que o valor do PWM nunca passe dos limites de 8 bits (-255 a 255)
    if (pwm_value > 255) pwm_value = 255;
    if (pwm_value < -255) pwm_value = -255;

    bool forward = (pwm_value >= 0);
    uint32_t duty_cycle = std::abs(pwm_value);

    // Direcionamento do sinal dependendo do motor escolhido
    if (side == MOTOR_LEFT) {
        if (pwm_value == 0) {
            // Frenagem Eletromagnética Ativa: Aciona ambos os polos (IN=1) em PWM máximo para dissipar inércia
            gpio_set_level(PIN_MOTOR_L_IN3, 1);
            gpio_set_level(PIN_MOTOR_L_IN4, 1);
            ledc_set_duty(PWM_MODE, PWM_CHANNEL_LEFT, 255);
        } else {
            // MODO ACELERAÇÃO
            gpio_set_level(PIN_MOTOR_L_IN3, forward ? 1 : 0);
            gpio_set_level(PIN_MOTOR_L_IN4, forward ? 0 : 1);
            ledc_set_duty(PWM_MODE, PWM_CHANNEL_LEFT, duty_cycle);
        }
        ledc_update_duty(PWM_MODE, PWM_CHANNEL_LEFT);
    } else {
        if (pwm_value == 0) {
            // Frenagem Eletromagnética Ativa
            gpio_set_level(PIN_MOTOR_R_IN1, 1);
            gpio_set_level(PIN_MOTOR_R_IN2, 1);
            ledc_set_duty(PWM_MODE, PWM_CHANNEL_RIGHT, 255);
        } else {
            // MODO ACELERAÇÃO
            gpio_set_level(PIN_MOTOR_R_IN1, forward ? 1 : 0);
            gpio_set_level(PIN_MOTOR_R_IN2, forward ? 0 : 1);
            ledc_set_duty(PWM_MODE, PWM_CHANNEL_RIGHT, duty_cycle);
        }
        ledc_update_duty(PWM_MODE, PWM_CHANNEL_RIGHT);
    }
}

void motor_disable() {
    // 1. Zera o PWM de ambos os motores
    ledc_set_duty(PWM_MODE, PWM_CHANNEL_LEFT, 0);
    ledc_update_duty(PWM_MODE, PWM_CHANNEL_LEFT);
    ledc_set_duty(PWM_MODE, PWM_CHANNEL_RIGHT, 0);
    ledc_update_duty(PWM_MODE, PWM_CHANNEL_RIGHT);

    // 2. Desliga os pinos de direção (freio passivo/costing)
    gpio_set_level(PIN_MOTOR_L_IN3, 0);
    gpio_set_level(PIN_MOTOR_L_IN4, 0);
    gpio_set_level(PIN_MOTOR_R_IN1, 0);
    gpio_set_level(PIN_MOTOR_R_IN2, 0);

    // 3. Corta o ENABLE físico da ponte H se estiver configurado
    if (PIN_MOTOR_ENABLE != GPIO_NUM_MAX) {
        gpio_set_level((gpio_num_t)PIN_MOTOR_ENABLE, 0); 
    }
}

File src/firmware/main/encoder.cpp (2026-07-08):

#include "encoder.hpp"

#include "driver/gpio.h"
#include "esp_attr.h"
#include "esp_timer.h"
#include <math.h>

// Pinos do Encoder (Motor Esquerdo)
#define ENC_LEFT_A   GPIO_NUM_17
#define ENC_LEFT_B   GPIO_NUM_16

// Pinos do Encoder (Motor Direito)
#define ENC_RIGHT_A  GPIO_NUM_18
#define ENC_RIGHT_B  GPIO_NUM_5

static volatile int32_t left_ticks = 0;
static volatile int32_t right_ticks = 0;

// Interrupção de hardware (ISR) acionada na borda de subida do canal A. 
// O nível lógico do canal B determina a direção da rotação.
static void IRAM_ATTR left_encoder_isr(void *arg)
{
    int b = gpio_get_level(ENC_LEFT_B);

    if (b)
        left_ticks++;
    else
        left_ticks--;
}

// Interrupção de hardware (ISR) acionada na borda de subida do canal A. 
// O nível lógico do canal B determina a direção da rotação.
static void IRAM_ATTR right_encoder_isr(void *arg)
{
    int b = gpio_get_level(ENC_RIGHT_B);

    // Leitura invertida via software para corrigir pinagem física invertida
    if (b)
        right_ticks--;
    else
        right_ticks++;
}

void encoder_init()
{
    gpio_config_t io_conf = {};

    io_conf.mode = GPIO_MODE_INPUT;
    io_conf.pull_up_en = GPIO_PULLUP_ENABLE;
    io_conf.intr_type = GPIO_INTR_POSEDGE;

    io_conf.pin_bit_mask =
        (1ULL << ENC_LEFT_A) |
        (1ULL << ENC_LEFT_B) |
        (1ULL << ENC_RIGHT_A) |
        (1ULL << ENC_RIGHT_B);

    gpio_config(&io_conf);

    gpio_install_isr_service(0);

    gpio_isr_handler_add(
        ENC_LEFT_A,
        left_encoder_isr,
        nullptr);

    gpio_isr_handler_add(
        ENC_RIGHT_A,
        right_encoder_isr,
        nullptr);
}

int32_t encoder_get_left_ticks()
{
    return left_ticks;
}

int32_t encoder_get_right_ticks()
{
    return right_ticks;
}

// --- Constantes de Conversão de Odometria ---
#define TICKS_POR_VOLTA 330.0f 
// Roda de 45mm de diâmetro -> 45 * PI = 141.37 mm = 14.137 cm
#define CM_POR_VOLTA 14.137f

// Cálculo da velocidade instantânea via aproximação temporal (Delta de Distância / Delta de Tempo) 
// usando o timer de hardware de alta resolução (esp_timer).
float encoder_get_left_velocity_cms()
{
    static int32_t last_left = 0;
    static uint64_t last_time = 0;

    const uint64_t now = esp_timer_get_time();
    if (last_time == 0) {
        last_time = now;
        last_left = left_ticks;
        return 0.0f;
    }

    float dt = (now - last_time) / 1000000.0f;
    if (dt <= 0.0f) return 0.0f;

    int32_t left_now = left_ticks;
    int32_t delta_left = left_now - last_left;

    last_left = left_now;
    last_time = now;

    float distance_cm = (delta_left / TICKS_POR_VOLTA) * CM_POR_VOLTA;
    return distance_cm / dt;
}

float encoder_get_right_velocity_cms()
{
    static int32_t last_right = 0;
    static uint64_t last_time = 0;

    const uint64_t now = esp_timer_get_time();
    if (last_time == 0) {
        last_time = now;
        last_right = right_ticks;
        return 0.0f;
    }

    float dt = (now - last_time) / 1000000.0f;
    if (dt <= 0.0f) return 0.0f;

    int32_t right_now = right_ticks;
    int32_t delta_right = right_now - last_right;

    last_right = right_now;
    last_time = now;

    float distance_cm = (delta_right / TICKS_POR_VOLTA) * CM_POR_VOLTA;
    return distance_cm / dt;
}

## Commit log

2026-04-23 organizando para adequar a nova estrutura e não perdermos o commit
2026-04-23 docs: adicona a documentação de requisitos de software (ref #18)
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2026-04-25 doc: criação do manual de boas práticas de markdown
2026-04-25 doc: criação do manual de boas práticas de markdown (ref #24)
2026-04-25 doc: estrutura inicial do documento de backend (ref #14)
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2026-04-27 docs: adição do arquivo .md que resolve a Atividade 1.1.2.1: Front-end
    Co-authored by: Sauhan <242024923@aluno.unb.br>
2026-04-28 doc: adição do tópico de integração com eletrônica (ref: #18
2026-04-28 Adiciona levantamento completo de requisitos - issue #20
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2026-05-04 Fix: Colocando arquivo de requisitos de estruturas dentro do mkdocs
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2026-05-05 docs: adicionando comparação entre o consumo dos sensores (ref #72)
2026-05-05 docs(#74): adiciona os cálculos realizados para o dimensionamento energético
2026-05-05 [docs] manual: integrar manual de git/github na main
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2026-05-07 Create projeto_labirinto.md
    Desenvolvimento de um labirinto modular de teste para competições de micromouse, detalhando os requisitos técnicos, dimensões, materiais utilizados, estrutura de construção, sistema de postes removív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
2026-05-08 docs: adição do arquivo .md que transforma os requisitos em histórias de usuário, e cria alguns testes, na pasta mkdocs/docs/software
2026-05-08 docs: adição do arquivo .md sobre algoritmos de solução dos labirintos
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2026-05-09 Revert "docs:Diagrama de estados"
2026-05-09 Revert "Revert "docs:Diagrama de estados""
2026-05-09 adição dos requisitos unificados de todas as áreas
2026-05-09 add: esquema eletrico (kicad)
    [pi1.kicad_pcb, pi1.kicad_sch]
2026-05-10 Add files via upload
    Arquivos CAD 2D e 3D do XaropinhoV1
    [Bateria.CATPart, Chassis.CATPart, Conversor DC-DC .CATPart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]
2026-05-10 docs: refatora arquitetura de dados e nomenclaturas do InfluxDB
2026-05-11 Modelagem 3D do labirinto
    Modelagem 3D do labirinto 4×4 para testes do robô Micromouse — PI1 2026/1 | FCTE/UnB. Desenvolvido em CATIA V5.
2026-05-12 adiciona arquivos em latex ao repositorio
    o relatorio foi feito no overleaf afim de facilitar a edição por várias pessoas
2026-05-24 feat: HU 2.1 - visualização de posição e orientação em tempo real (#103)
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2026-05-25 [feat] mapa: (#103) adiciona visualização de posição e orientação em tempo real
2026-05-25 [feat] fsm: (#105) adiciona monitoramento da máquina de estados
2026-05-25 [feat] fsm: (#105) adiciona arquivos de estilização e estuturação
2026-05-25 feat: configuracao do banco de dados InfluxDB e backend receptor UDP
2026-05-28 feat: implementação do flood fill junto a api que vai conectar no simulador
2026-05-28 docs: adicona comentário explicativo para cada função em src/firmware/simulador/Main.cpp
2026-05-30 fix: problema do rato ficando preso nas paredes
    [Main.cpp]
2026-06-01 feat: implementacao de telemetria udp assincrona usando freertos e msgpack
2026-06-01 fix#166: adiciona a criacao do json ao codigo flod fill
    [Main.cpp]
2026-06-01 fix: corrige caminho pro json
    [Main.cpp]
2026-06-02 feat: integração do hsitorico com json de registro de corrida
2026-06-04 feat(telemetria): adiciona paineis do grafana e refatora mock de dados
2026-06-04 Revert "feat(telemetria): adiciona paineis do grafana e refatora mock de dados"
2026-06-05 [feat] frontend: (#180) eleva estado e integra fluxo de telemetria via mock fsm
2026-06-05 [feat] frontend: (#180) altera arquivos de configuração do frontend
2026-06-06 feat: Implementa layout adaptativo de alta performance (HU 2.4) e alertas de bateria crítica (HU 3.2.1)
2026-06-07 Adição do servidor HTTP que recebe via UDP, utilizando sockets
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2026-06-07 test(#206): teste de registo de célula dentro da pasta firmware
2026-06-07 test(205): adiciona testes de inicializacao do labirinto para grids 4x4, 8x8 e 16x16
2026-06-07 [test] e2e: adiciona testes do dashboard (simulação e modos de operação)
2026-06-07 [test] e2e(frontend): (#202) implementa testes da página de histórico e replay
2026-06-07 [test] e2e(frontend): (#202) adiciona testes de navegação e utilitários compartilhados
2026-06-08 feat(backend): automacao da geracao de json do historico (closes #118, closes #139)
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2026-06-08 feat(#204): testes de funções auxiliares do Flood Fill
2026-06-08 docs: adiciona caminho para documentação de testes de software
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2026-06-08 fix: ajustes nos arquivos referentes ao algoritmo e testes do algoritmo
    [Main.cpp]
2026-06-09 test: adiciona testes de decode MsgPack e Mapeamento dinamico (Resolves #212, #213)
2026-06-09 test: adiciona testes Catch2 para Flood Fill (Resolves #207, #209)
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2026-06-10 feat(firmware): implementa Ring-Buffer offline e envio em lote via MsgPack
    - Criação do Ring-Buffer (capacidade de 600 pacotes/60s) para armazenar telemetria localmente em quedas de Wi-Fi.
    - Implementação de algoritmo de envio em lote (Batch Dispatcher) comprimido via MsgPack quando a conexão é restabelecida.
    - Correção do tamanho de `tx_buffer` (4096 bytes) para suportar lotes maiores sem truncação no UDP.
    - Configuração do gateway `host.wokwi.internal`
    - Refatoração dos comentários do firmware seguindo práticas de Clean Code.
    - Atualização do `Makefile` para usar o entrypoint correto do backend (`telemetryService.js`).
2026-06-10 fix(tests): correcoes nos testes do backend e frontend e atualizacao do Makefile
    - Corrige caminhos de importacao no backend devido a refatoracao do telemetryService.
    - Corrige teste do backend (msgpack_mapping) para refletir a nova logica de timestamp em ms em vez de s.
    - Corrige typo no import do componente FSMStatus no teste do frontend.
    - Adiciona os comandos test-backend, test-frontend e test-firmware ao Makefile.
2026-06-10 chore: remove pasta de build dos testes em c++ do git tracking
2026-06-11 fix(historico): aprimora gerador de JSON com tamanho de grid, nomes de arquivo e rota do mock coerente
    [Main.cpp]
2026-06-14 chore(config): atualiza arquivos de configuração e configura rotas de mock no vite
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2026-06-17 feat: adição de caminhos rota_calculada para os testes de FAST_RUN no mock_sender.js, e adição da dependência detonov ao package-lock.json e package.json
2026-06-17 fix(tests): ajusta testes do frontend apos refatoracoes de UI e utils
2026-06-17 fix: conexão do backend com o front
    [telemetry.cpp]
2026-06-18 fix: corrige carregamento de corridas e valida 4×4/8×8/16×16(#179)
    [Main.cpp]
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2026-06-19 fix(#179): resolve problema de visualização corrigindo dados mockados
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2026-06-24 fix: adiciona switches.cpp ao CMakeLists.txt
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2026-07-03 feat: implementacao da FSM de mapeamento e Wall Following no controle de celula
2026-07-03 feat: leitura dinamica da chave de tamanho do labirinto no estado IDLE
2026-07-03 refactor: centraliza envio de telemetria no movement.cpp anexando dados dos motores via getters
2026-07-06 fix: adiciona valores dos TOFs no log do terminal em tempo real
    [telemetry.cpp]
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2026-07-06 Fix: vários fix em portas em ticks em graus
    [movement.cpp, navigation.cpp, switches.cpp]
